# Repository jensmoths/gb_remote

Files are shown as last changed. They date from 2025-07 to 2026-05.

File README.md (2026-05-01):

# GB Remote

<div align="center">
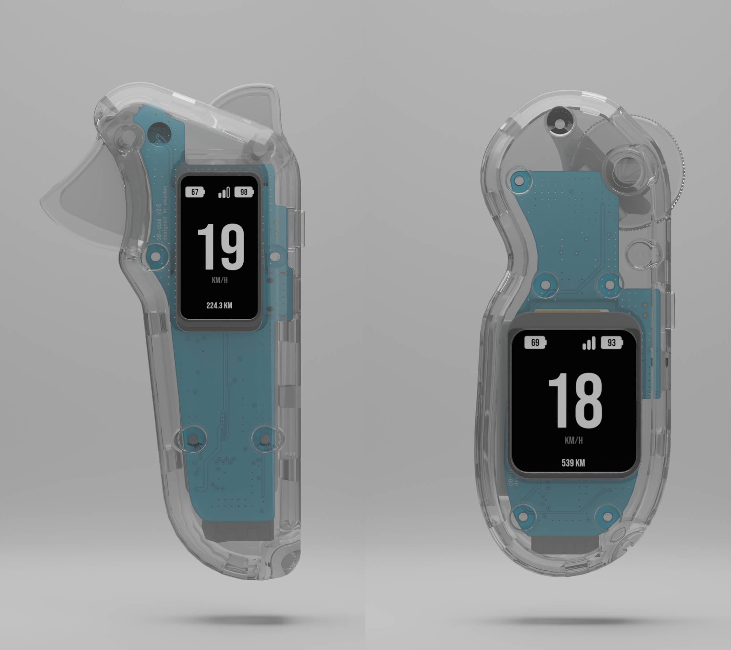
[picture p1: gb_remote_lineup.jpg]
GB Controller
  
</div>

A firmware open-source hand controller for electric skateboards built with the ESP32S3. This project provides a complete wireless control solution with real-time telemetry monitoring, featuring a custom BLE protocol that communicates with VESC motor controllers and Jiabaida/Kaly BMS systems.

This repository contains the **remote controller firmware**. The complete system also includes:
- **Receiver Firmware** (`gb_receiver`): The BLE server firmware that runs on the receiver

## Key Features

### Intuitive Control Interface
- **Analog Throttle Control**: High-precision ADC-based throttle input with automatic calibration
- **Dual Throttle Support**: Separate throttle and brake inputs on dual throttle variant with neutral position
- **Smart Button Interface**: Multi-function button with long-press and double-press detection
- **Haptic Feedback**: Vibration patterns for connection status, alerts, and user feedback
- **Sleep Management**: Automatic power management with inactivity detection and power modes
- **Power Management**: Soft latching hardware where power consumption while "sleeping is 1uA"

### Modern UI
- **LVGL Graphics Library**: Beautiful, responsive user interface built with EEZ Studio (open-source)
- **Real-time Speed Display**: Large, easy-to-read speedometer with km/h and mi/h display
- **Dual Battery Monitoring**: Separate battery indicators for controller and skateboard
- **Connection Status**: Visual feedback for BLE connection quality
- **Trip Distance Tracking**: Built-in odometer with persistent storage
- **Adjustable Backlight**: Configurable display brightness (1-100%)

### Comprehensive Telemetry
- **VESC Integration**: Real-time data from VESC
- **BMS Support**: Full battery management system monitoring with cell-level voltage tracking
  - **Compatible BMS Systems**: Jiabaida and Kaly BMS telemetry support
  - **Cell Voltage Monitoring**: Individual cell voltage tracking for up to 16 cells
  - **Capacity Tracking**: Real-time remaining and nominal capacity monitoring
- **Custom BLE Protocol**: Optimized data transmission for low latency and high reliability
- **Automatic Parameter Configuration**: Motor pulley, wheel diameter, and throttle settings are automatically retrieved by the receiver from the vesc

## Hardware Variants

The firmware supports two hardware variants:

### GB Remote Lite
- **Display**: 240×320 pixel TFT LCD
- **Throttle**: Single analog throttle with inversion support
- **Use Case**: Standard single-throttle control

### GB Remote Dual Throttle
- **Display**: 172×320 pixel TFT LCD
- **Throttle**: Dual analog inputs (throttle + brake)
- **Use Case**: Separate throttle and brake control with neutral position

Both variants share the same core firmware with target-specific configurations.

## Technical Specifications

### Hardware Platform
- **MCU**: ESP32 S3
- **Display**: TFT LCD ST7789 (resolution varies by variant)
- **Input**: Analog throttle with ADC calibration (dual inputs on dual throttle variant)
- **Connectivity**: Bluetooth Low Energy (BLE) SPP client
- **Power**: Built-in battery monitoring and power management
- **Haptic Feedback**: Vibration motor for user notifications

### Software Architecture
- **RTOS**: FreeRTOS for real-time task management
- **Graphics**: LVGL 8.3.6 with EEZ Studio UI
- **Communication**: Custom BLE SPP protocol for VESC/BMS data
- **Storage**: NVS flash for configuration and trip data
- **Power Management**: Advanced power modes and soft latching circuit

## Communication Protocol

### BLE SPP Protocol
- **Service UUID**: `0xABF0`
- **Data Characteristic**: `0xABF2`
- **Protocol**: Custom BLE SPP for low-latency communication with receiver
- **Data Exchange**: Throttle/brake commands from remote, VESC and BMS telemetry from receiver

### BLE Pairing Phrase
The receiver and remote can use a shared text pairing phrase. BLE SMP still uses a 6-digit numeric passkey internally; both sides derive that passkey from the exact phrase bytes using FNV-1a 32-bit and `hash % 1000000`.

- Configure the **same phrase** on both `gb_receiver` and this remote.
- The phrase is case-sensitive and may contain 1–32 printable characters.
- If no phrase is configured on the remote, it remains backward-compatible with the legacy passkey `483265`.
- After changing the phrase, remove/forget old BLE pairings on both sides and pair again.

Remote CLI examples over USB serial:

```text
cli
set ble_pairing_phrase my shared phrase
get ble_pairing_phrase
set ble_pairing_phrase_clear 1
set ble_clear_bonds 1
```

`get ble_pairing_phrase` shows the derived numeric value, for example `Derived BLE passkey: 042317`, so it can be compared with the receiver UI.

### USB Serial Binary Protocol
The remote communicates with the configuration tool via a binary protocol over USB Serial (USB CDC):

- **Packet-based**: Binary protocol with CRC-16-CCITT error checking
- **Real-time Streaming**: Configurable data streaming (1-100 Hz) for monitoring and debugging
- **Commands**: Firmware version, configuration management, calibration, odometer control, BLE trim adjustment
- **Documentation**: See [`firmware/docs/USB_SERIAL_PROTOCOL.md`](firmware/docs/USB_SERIAL_PROTOCOL.md) for complete protocol specification

## Project Structure

This repository contains the **remote controller firmware**. The complete GB Remote system consists of:

1. **Remote Controller** (this repository): ESP32S3-based hand controller with display and throttle
2. **Receiver Firmware** (`gb_receiver`): BLE server firmware for the skateboard/receiver side that interfaces with VESC and BMS

## Getting Started

### Prerequisites
- ESP-IDF development environment

### Build & Flash

The project includes build scripts for easy compilation:

- **Lite variant**: `./lite_build.sh` - Builds for 240×320 display with single throttle
- **Dual Throttle variant**: `./dual_throttle_build.sh` - Builds for 172×320 display with dual throttle/brake
- **Release build**: `./build_and_release.sh` - Builds both variants for release

After building, flash using ESP-IDF:
```bash
idf.py flash monitor
```

Or use the [Configuration Tool](https://gbengineering.se/config-tool/) for easy firmware updates.

## Configuration Tool

**Easy Configuration via Web Interface**

Configure your GB Remote controller easily using our online configuration tool hosted on the GB Engineering website:

**[GB Remote Configuration Tool](https://gbengineering.se/config-tool/)**

The configuration tool provides a comprehensive web-based interface for setting up and managing your GB Remote system.

### Features:
- **USB Serial Connection**: Connect directly via USB cable
- **Real-time Configuration**: Adjust settings without recompiling firmware
- **Automatic Firmware Updates**: The configuration tool automatically checks for firmware updates every time the remote is connected. Update with a simple button confirmation
- **Throttle Calibration**: Calibrate throttle and brake inputs with guided calibration process
- **Speed Unit Toggle**: Switch between km/h and mph display units
- **Backlight Control**: Adjustable display brightness (0-100%)
- **BLE Trim Adjustment**: Fine-tune BLE output offset for precise throttle control
- **BLE Pairing Phrase**: Configure the receiver/remote pairing phrase via the USB serial CLI
- **Odometer Management**: Reset trip distance counter
- **Real-time Data Streaming**: Monitor live telemetry data at configurable rates (1-100 Hz)
- **Status Monitoring**: Real-time device status and logs

### Quick Setup:
1. Flash the firmware to your Remote (and Receiver if needed)
2. Connect your controller via USB cable
3. Open the [Configuration Tool](https://gbengineering.se/config-tool/)
4. Click "Connect to Remote" to establish USB serial connection
5. Configure your settings and calibrate throttle

## BMS Compatibility

This controller is specifically designed to work with popular electric skateboard BMS systems:

- **Jaiabaida BMS**: Full telemetry support including cell voltages and capacity data
- **Kaly BMS**: Complete compatibility with all monitoring features

The receiver firmware (`gb_receiver`) handles the BMS communication and forwards the telemetry data to the remote controller via BLE.

## Contributing

This project is open source and welcomes contributions! Whether you're fixing bugs, adding features, or improving documentation, your help is appreciated.

### Pre-commit hooks

To enable auto-formatting (trailing whitespace trim + clang-format on C/C++ files) before each commit:

```bash
git config core.hooksPath githooks
```

Requires [clang-format](https://clang.llvm.org/docs/ClangFormat.html) (e.g. `brew install clang-format` on macOS).

## License

**Creative Commons Attribution-NonCommercial 4.0 International (CC BY-NC 4.0)**

This work is licensed under the Creative Commons Attribution-NonCommercial 4.0 International License. To view a copy of this license, visit [http://creativecommons.org/licenses/by-nc-nd/4.0/](http://creativecommons.org/licenses/by-nc-nd/4.0/).

### What this means:

**You are free to:**
- Share - copy and redistribute the material in any medium or format
- Adapt - remix, transform, and build upon the material
- Use for personal, educational, and research purposes

**You may NOT:**
- Use for commercial purposes (selling, commercial distribution, etc.)
- Create derivative works (modify and redistribute)
- Use without proper attribution to the original author

### Commercial Use:
For commercial use, licensing, or commercial distribution of this project, please contact the author for licensing terms and fees.

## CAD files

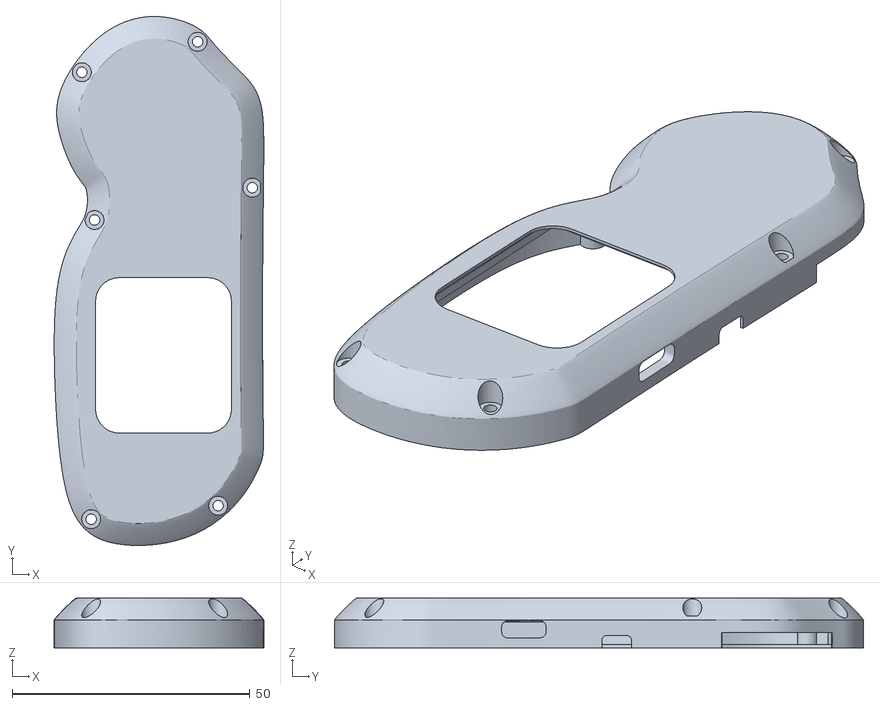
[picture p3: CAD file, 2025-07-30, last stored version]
mechanics/front.stl
44.1 x 111.3 x 10.5

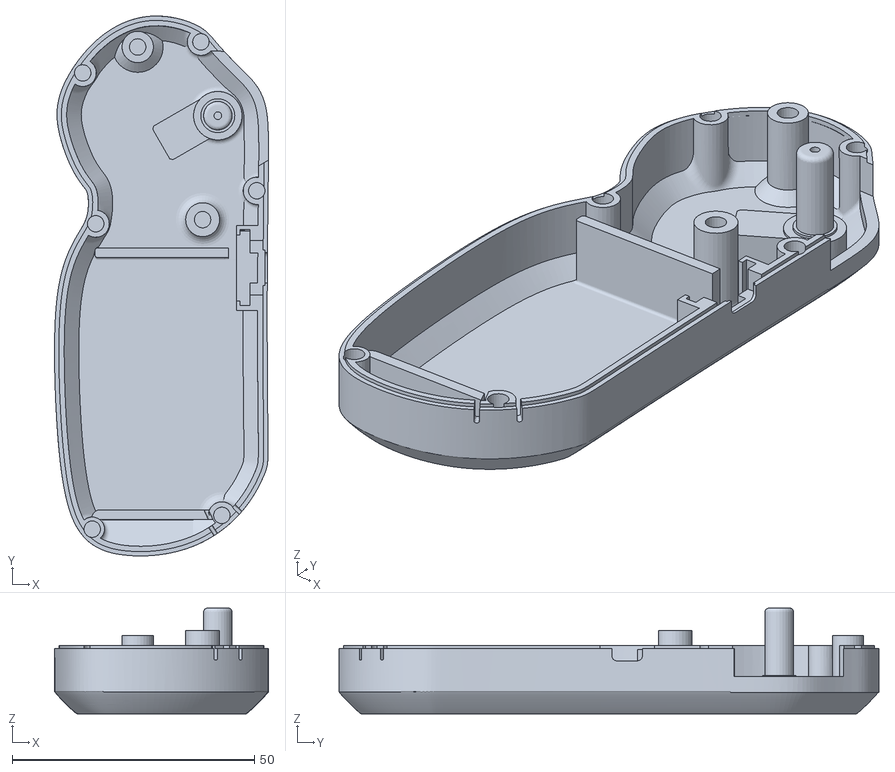
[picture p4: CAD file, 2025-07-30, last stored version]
mechanics/back.stl
44.1 x 111.3 x 21.8

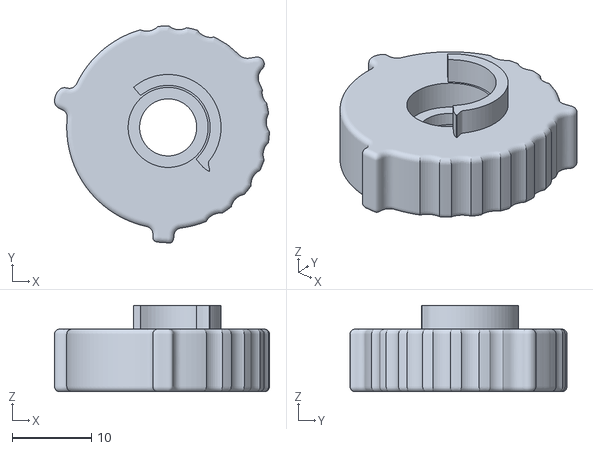
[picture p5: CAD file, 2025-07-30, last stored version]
mechanics/throttle.stl
27.1 x 27.4 x 10.9

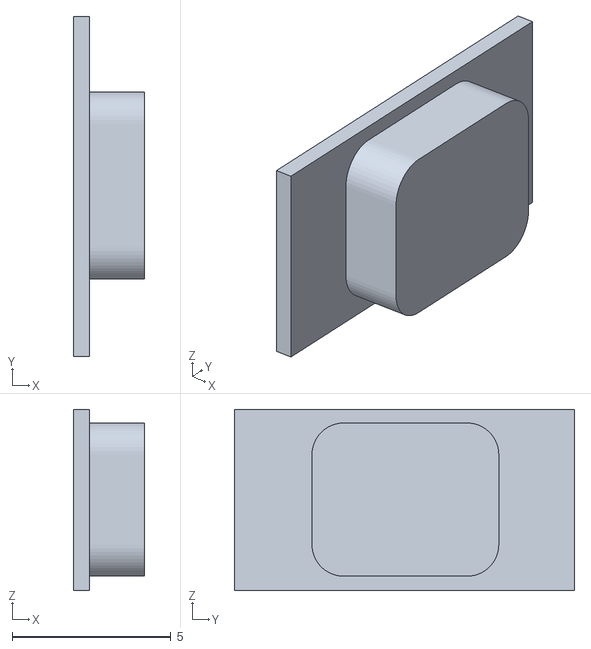
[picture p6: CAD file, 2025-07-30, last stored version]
mechanics/power_button.stl
2.23 x 10.7 x 5.70

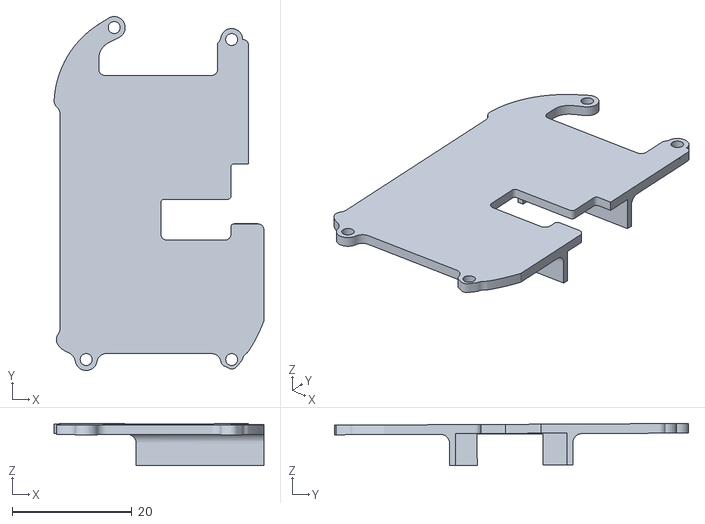
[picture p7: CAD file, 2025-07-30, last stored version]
mechanics/display_cover.stl
35.0 x 59.1 x 7.02

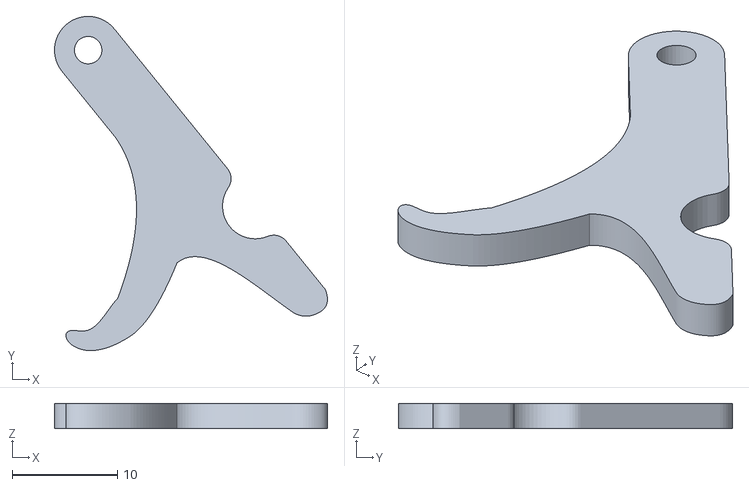
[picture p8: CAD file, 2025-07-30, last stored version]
mechanics/retreat.stl
25.9 x 31.7 x 2.40

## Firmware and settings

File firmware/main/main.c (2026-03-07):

/**
 * @file main.c
 * @brief Main entry point for the GB Remote firmware
 *
 * Two power modes:
 * - Charging mode: minimal init (battery, LCD, UI). Show charging screen;
 *   block until long-press (→ full boot) or USB disconnect (→ sleep).
 * - Full mode: all subsystems (BLE, throttle, comms). Home/splash, inactivity
 *   timeout, charging screen USB monitoring.
 */

#include "app_init.h"
#include "ble.h"
#include "freertos/FreeRTOS.h"
#include "freertos/task.h"
#include "power.h"

void app_main(void) {
  app_init_log_startup();
  app_init_early();
  app_run_charging_mode(); /* Blocks until full boot or sleep */

  app_init_after_charging();

  for (;;) {
    power_check_charging_screen_usb();
    /* Inactivity only considers BLE when in full mode; on charging screen BLE
     * is off. */
    power_check_inactivity(power_get_mode() == POWER_MODE_FULL &&
                           ble_is_connected());
    vTaskDelay(pdMS_TO_TICKS(100));
  }
}

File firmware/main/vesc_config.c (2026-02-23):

#include "vesc_config.h"
#include "ble.h"
#include "esp_log.h"
#include "nvs.h"
#include "nvs_flash.h"
#include <math.h>

#define TAG "VESC_CONFIG"

// Current motor config from VESC (volatile, updated via BLE)
static vesc_motor_config_t current_motor_config = {
    .motor_poles = 10,        // Default until VESC sends config
    .gear_ratio_x1000 = 1000, // Default until VESC sends config
    .wheel_diameter_mm = 100, // Default until VESC sends config
};

// Default user preferences (saved to NVS)
static const vesc_config_t default_config = {
    .motor_poles = 11,        // Will be overwritten by VESC
    .gear_ratio_x1000 = 1001, // Will be overwritten by VESC
    .wheel_diameter_mm = 101, // Will be overwritten by VESC
    .speed_unit_mph = false,  // Speed unit: km/h by default
#ifdef CONFIG_TARGET_LITE
    .invert_throttle = false // Throttle inversion disabled by default
#endif
};

esp_err_t vesc_config_init(void) {
  // Try to load user preferences, if it fails (first time) save defaults
  vesc_config_t config;
  esp_err_t err = vesc_config_load(&config);

  if (err == ESP_ERR_NVS_NOT_FOUND) {
    ESP_LOGI(TAG, "No user preferences found, saving defaults");
    return vesc_config_save(&default_config);
  }

  return err;
}

esp_err_t vesc_config_load(vesc_config_t *config) {
  nvs_handle_t nvs_handle;
  esp_err_t err;

  // Start with current motor config from VESC (or defaults if not yet received)
  config->motor_poles = current_motor_config.motor_poles;
  config->gear_ratio_x1000 = current_motor_config.gear_ratio_x1000;
  config->wheel_diameter_mm = current_motor_config.wheel_diameter_mm;

  // Set default user preferences
  config->speed_unit_mph = false;
#ifdef CONFIG_TARGET_LITE
  config->invert_throttle = false;
#endif

  // Load user preferences from NVS
  err = nvs_open(VESC_NVS_NAMESPACE, NVS_READONLY, &nvs_handle);
  if (err != ESP_OK) {
    // No NVS data, use defaults - this is OK
    return (err == ESP_ERR_NVS_NOT_FOUND) ? ESP_OK : err;
  }

  uint8_t speed_unit;
  err = nvs_get_u8(nvs_handle, NVS_KEY_SPEED_UNIT, &speed_unit);
  if (err == ESP_OK) {
    config->speed_unit_mph = (bool)speed_unit;
  }

#ifdef CONFIG_TARGET_LITE
  uint8_t invert_throttle;
  err = nvs_get_u8(nvs_handle, NVS_KEY_INVERT_THROTTLE, &invert_throttle);
  if (err == ESP_OK) {
    config->invert_throttle = (bool)invert_throttle;
  }
#endif

  nvs_close(nvs_handle);
  return ESP_OK;
}

esp_err_t vesc_config_save(const vesc_config_t *config) {
  nvs_handle_t nvs_handle;
  esp_err_t err;

  // Only save user preferences to NVS (NOT motor config from VESC)
  err = nvs_open(VESC_NVS_NAMESPACE, NVS_READWRITE, &nvs_handle);
  if (err != ESP_OK)
    return err;

  err = nvs_set_u8(nvs_handle, NVS_KEY_SPEED_UNIT,
                   (uint8_t)config->speed_unit_mph);
  if (err != ESP_OK)
    goto cleanup;

#ifdef CONFIG_TARGET_LITE
  err = nvs_set_u8(nvs_handle, NVS_KEY_INVERT_THROTTLE,
                   (uint8_t)config->invert_throttle);
  if (err != ESP_OK)
    goto cleanup;
#endif

  err = nvs_commit(nvs_handle);

cleanup:
  nvs_close(nvs_handle);
  return err;
}

void vesc_config_update_motor(uint8_t motor_poles, uint16_t gear_ratio_x1000,
                              uint16_t wheel_diameter_mm) {
  if (motor_poles != current_motor_config.motor_poles ||
      gear_ratio_x1000 != current_motor_config.gear_ratio_x1000 ||
      wheel_diameter_mm != current_motor_config.wheel_diameter_mm) {

    current_motor_config.motor_poles = motor_poles;
    current_motor_config.gear_ratio_x1000 = gear_ratio_x1000;
    current_motor_config.wheel_diameter_mm = wheel_diameter_mm;

    ESP_LOGI(
        TAG,
        "Motor config from VESC: poles=%d, gear_ratio=%.3f, wheel_diam=%dmm",
        motor_poles, gear_ratio_x1000 / 1000.0f, wheel_diameter_mm);
  }
}

void vesc_config_get_motor(vesc_motor_config_t *motor_config) {
  if (motor_config != NULL) {
    motor_config->motor_poles = current_motor_config.motor_poles;
    motor_config->gear_ratio_x1000 = current_motor_config.gear_ratio_x1000;
    motor_config->wheel_diameter_mm = current_motor_config.wheel_diameter_mm;
  }
}
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

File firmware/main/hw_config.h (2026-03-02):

#ifndef HW_CONFIG_H
#define HW_CONFIG_H

#include "driver/gpio.h"

// ADC channel definitions
#define THROTTLE_PIN ADC_CHANNEL_8
#define BRAKE_PIN ADC_CHANNEL_7

// Battery ADC channel
#define BATTERY_VOLTAGE_PIN ADC_CHANNEL_0

// Button GPIO definitions
#define MAIN_BUTTON_GPIO GPIO_NUM_10

// Power off GPIO definition
#define POWER_HOLD_GPIO GPIO_NUM_4

// Battery status GPIO
#define BATTERY_IS_CHARGING_GPIO GPIO_NUM_2
#define BATTERY_PROBE_PIN GPIO_NUM_7

// USB charger plug detection GPIO
#define USB_DETECT_GPIO GPIO_NUM_12

// TFT display GPIO definitions
#define TFT_MOSI_PIN GPIO_NUM_17
#define TFT_SCLK_PIN GPIO_NUM_16
#define TFT_CS_PIN GPIO_NUM_15
#define TFT_DC_PIN GPIO_NUM_14
#define TFT_RST_PIN GPIO_NUM_18
#define TFT_BL_PIN GPIO_NUM_13

// Viber GPIO definition
#define VIBER_PIN GPIO_NUM_6

#endif // HW_CONFIG_H

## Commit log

2025-07-30 adding mech
    [back.stl, display_cover.stl, front.stl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]
2025-08-14 adding GUI tool and pid level ing assist
2025-08-15 hw_config: updating bms uart pins
2025-08-26 fixing partition size to fit coredump on flash
    [partitions.csv]
2025-09-13 level_assistant: cleanup on adaptive pid
2025-09-13 level_assistant: taming pid gains
2025-09-19 fixing mi/h and km/h text on UI at boot
    [main.c, vesc_config.c]
2025-09-19 fixing battery level calibration
    [battery.c, battery.h]
2025-10-15 cleanup, removed pid from level assistant
2025-10-16 porting to EEZ Studio
    [partitions.csv]
2025-10-16 refusing calibration process if user didnt move the throttle full span
2025-10-16 dont send throttle if nvs empty or not calibrated
2025-10-31 fixing adc wrongly naming, replace with throttle name instead
    [battery.c, battery.h, hw_config.h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]
2025-10-31 fix generic function naming from adc to throttle
    [throttle.c, throttle.h]
2025-11-01 inverting screen 180 degrees
    [lcd.c]
2025-11-01 removing invert throttle
2025-11-02 combining throttle and brake into ble output
2025-11-02 adding power module, adding vesc voltage display if bms is not connected
2025-11-02 building for lite and dual throttle on the same project
2025-11-02 adding throttle and ble handling for targets
2025-11-02 fix stack overflow on button task
    [button.c, main.c]
2025-11-03 fixing backlight levels and flash script
    [lcd.c, lcd.h, main.c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]
2025-11-03 ui_updater: fix unused function
    [ui_updater.c, ui_updater.h]
2025-11-04 fix buildtree
    [back.stl, display_cover.stl, front.stl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]
2025-11-06 cleanup on throttle module, added battery voltage monitoring to ui
2025-11-11 fix timing on the ui tasks to have more stability
    [lcd.c, main.c, throttle.c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]
2025-11-12 fix ui functions not taking mutex first
    [ui_updater.c]
2025-11-12 power: rename power gpio conf
2025-11-12 rework on power module
    [ble.c, button.c, hw_config.h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]
2025-11-18 viber: higher short pulsing time
    [viber.c]
2025-12-01 fix dual throttle calibration handling
2025-12-01 ui_updater: write to nvs when reset odometer
    [ui_updater.c]
2025-12-01 fix invert throttle
2025-12-05 shutdown wont be triggered if vesc speed > 0
2025-12-09 allow turning power off if speed is bigger than 0
2025-12-11 parse motor config from vesc
2025-12-11 replace direct mutex calls with command queue for all LVGL updates
    [power.c, ui_updater.c]
2025-12-11 fix calibration bug on dual throttle
    [ble.c, throttle.c, throttle.h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]
2025-12-11 rework on serial handler, motor config aquired from server at runtime
    [ble.c, vesc_config.c, vesc_config.h]
2025-12-13 add serial protocol, removed calibration margins
2025-12-13 dual throttle raw adc inverted logic
    [throttle.c]
2025-12-14 fix battery init in throttle
    [battery.c, battery.h, throttle.c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]
2025-12-14 power: inactivity timeout of 5 minutes
2025-12-14 add charging screen
2025-12-17 add trim command for throttle
2025-12-17 power: enable sleep
2025-12-17 ble: fix type-limits warning
    [ble.c]
2025-12-17 Add wake-up from sleep with long press on main button
    - Configure button GPIO as wake-up source before entering deep sleep
    - Add power_check_wake_from_sleep() to detect wake and verify long press
    - Require 500ms long press to turn device on after sleep
    - Add power_sleep_immediate() for quick sleep when wake-up check fails
    - Check wake-up status early in app_main() before full initialization
    [main.c, power.c, power.h]
2026-01-06 Fix: Invert trim offset when throttle is inverted
    When throttle inversion is enabled, the trim offset direction must also be inverted to maintain correct compensation. This ensures that trim adjustments work correctly regardless of throttle inversion state.
    [ble.c]
2026-01-09 Optimize task timings and add LVGL mutex protection
    - Reduce task frequencies to improve system stability:
    * ADC task: 20ms -> 30ms (50Hz -> 33Hz)
    * LVGL handler: 10ms -> 16ms (100Hz -> 62.5Hz)
    * USB serial: 10ms -> 20ms (100Hz -> 50Hz)
    * Button monitor: 10ms -> 20ms (100Hz -> 50Hz)
    * Speed update: 20ms -> 50ms (50Hz -> 20Hz)
    * BLE ADC send: 50ms -> 75ms (20Hz -> ~13Hz)
    - Add mutex protection for all LVGL screen switching operations:
    * power.c: Screen switching now thread-safe
    * button.c: Screen switching now thread-safe
    * Fixes race condition causing delayed home screen return
    - Fix variable scope in usb_serial.c (throttle_inverted)
    - Bump version to 1.2.0
    [ble.c, button.c, lcd.c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]
2026-01-10 Add coredump detection, upload flow, and automatic partition erasure
2026-01-11 added battery protection and register watchdog on all critical tasks
2026-01-23 Add BLE pairing and paired device persistence (v2.0.0)
    - Add NVS storage for paired server MAC address
    - Implement BLE security with passkey authentication (MITM protection)
    - Prioritize reconnecting to last paired device on startup/disconnect
    - Fall back to scanning for any device after 15 second timeout
    - Fix scan race condition by waiting for stop complete event before restarting
    - Remove unnecessary watchdog from connection update task
    [ble.c, ui_updater.c]
2026-01-26 fix button handling to interrupt based instead of polling
    [button.c]
2026-02-03 fix button_monitor task watchdog timeout and reduce BLE reconnect timeout
    - Fix watchdog trigger by replacing portMAX_DELAY with 4s timeout in button task
    - Add watchdog reset in startup button-release wait loop
    - Reduce BLE paired device reconnect timeout from 15s to 5s
    [ble.c, button.c]
2026-02-05 refactor: clean up main.c structure and improve modularity
    - Move backlight loading/fading to lcd.c (lcd_load_saved_brightness, lcd_fade_to_saved_brightness)
    - Move splash screen logic to ui_updater.c (ui_show_splash_screen)
    - Encapsulate power wake check inside power_init() - no longer exposed in header
    - Use ble_is_connected() instead of extern is_connect
    - Make error handling consistent: ESP_ERROR_CHECK for critical only (button, adc, battery)
    - Non-critical failures (viber, vesc_config) now log warnings and continue
    - Remove duplicate ui_update_aux_output_indicator call
    - main.c reduced from 166 to 119 lines, now pure orchestration
    [lcd.c, lcd.h, main.c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]
2026-02-05 fix: critical safety and reliability improvements
    CRITICAL SAFETY FIXES:
    - Fix LITE mode ADC error handling: errors now map to neutral (128), not throttle (0)
    - Block throttle transmission when battery is critically low
    - Add division-by-zero protection in map_throttle_value() and map_brake_value()
    THREAD SAFETY FIXES:
    - Replace all direct is_connect access with ble_is_connected() for mutex protection
    - throttle.c, power.c, ui_updater.c, usb_serial.c, ble.c (adc_send_task)
    RELIABILITY IMPROVEMENTS:
    - Add neutral dead zone (±3 units) to prevent unintended motion from ADC noise
    - Add watchdog registration to connection_update_task
    - Validate calibration values on NVS load (range, min<max,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
    [ble.c, power.c, throttle.c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]
2026-02-05 fix: improve BLE thread safety and ADC reliability
    - Replace direct is_connect access with thread-safe ble_is_connected()
    - Make is_connect static and remove extern declaration from header
    - Fix memory leak in MTU reconfig by freeing db before reallocation
    - Fix incorrect reconnect timeout log message (was hardcoded)
    - Improve throttle/brake ADC validation with min sample requirement
    - Add stuck-value detection for throttle/brake sensors
    - Add outlier rejection to battery ADC using trimmed mean
    [battery.c, ble.c, throttle.c]
2026-02-05 fix: resolve task watchdog timeouts in UI update tasks
    - Move watchdog reset to start of loop in all UI tasks
    - Split connection_update_task's 5s delay into 1s chunks
    - Ensures watchdog is reset before any potentially blocking operations
    The conn_update task was triggering watchdog because it slept for
    5 seconds (CONNECTION_UPDATE_MS) which equals the watchdog timeout.
    [ui_updater.c]
2026-02-05 refactor: improve code quality and industry standards compliance
    - Add named constants for magic number delays across all modules
    - Fix BREAK_PIN typo to BRAKE_PIN in hw_config.h and throttle.c
    - Replace extern variable with getter function (power_is_entering_off_mode)
    - Replace assert() with proper error handling in lcd.c buffer allocation
    - Remove dead code (unreachable vTaskDelete in ble.c)
    - Add comprehensive error handling documentation in main.c
    - Use volatile for shared state visibility across tasks
    - Remove watchdog from non-critical connection_update_task
    [battery.c, ble.c, hw_config.h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]
2026-02-15 swapped mi/h to mph
    [main.c, ui_updater.c, vesc_config.h]
2026-02-20 add interactive throttle calibration
2026-02-23 Run clang-format on power module
2026-02-23 Run clang-format on battery module
2026-02-23 Run clang-format on button module
2026-02-23 Run clang-format on throttle module
2026-02-23 Run clang-format on vesc_config module
2026-03-01 fix race in adc_send_task
    [ble.c]
2026-03-01 fix ble watchdog bug
    [ble.c]
2026-03-02 trying the charging screen implementation
2026-03-02 work on power modes
2026-03-03 fix ble throttle issue!
    [ble.c, hw_config.h, power.c]
2026-03-06 add throttle curves
2026-03-06 add brake curves
2026-03-06 fix throttle center point in lite
    [throttle.c]
2026-03-07 update on ui charging screen
2026-03-16 calibration update rate
2026-04-01 remove receiver-side reconnect preference logic
    Reconnect intelligence has moved to the receiver. Remote no longer saves
    or filters by receiver MAC — it simply scans for any GS-THUMB device on
    boot and after disconnect. Removes paired server NVS storage, reconnect
    timer, and reconnect handler task.
    [ble.c]
2026-04-07 moved odometer tracking to receiver side to support multiple boards
2026-04-09 fix adc calibration lock when empty flash
    [throttle.c]
2026-04-21 add 2 step power down routine
2026-04-23 dual stage faster power down
2026-04-23 fix lite power state ui icon location
2026-04-24 add throttle calibration error to UI
    [ui_updater.c, ui_updater.h]
2026-04-24 increase button double press time
2026-04-25 Fix shutdown completion feedback and timing
    [power.c]
2026-04-26 add reset odometer function to remote: odometer is saved into receiver nvs, remote sends a command to resets its odometer
    [ble.c]
2026-04-27 remove throttle/brake curves
2026-04-27 use per-target build dirs and sdkconfig files to avoid mutating shared config on target switch
2026-05-01 Fix startup and shutdown backlight fades
    [power.c, ui_updater.c]
2026-05-01 Add BMS BLE telemetry diagnostics
